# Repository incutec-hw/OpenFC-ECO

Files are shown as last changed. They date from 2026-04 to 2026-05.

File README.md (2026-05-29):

# OpenFC-Lite-Mini

Open-source Betaflight flight controller — **20×20 mm**, 6-layer, 3S–6S, built around the RP2354B microcontroller. Compact and low-cost: external RX over UART, microSD blackbox, analog OSD.

<p>
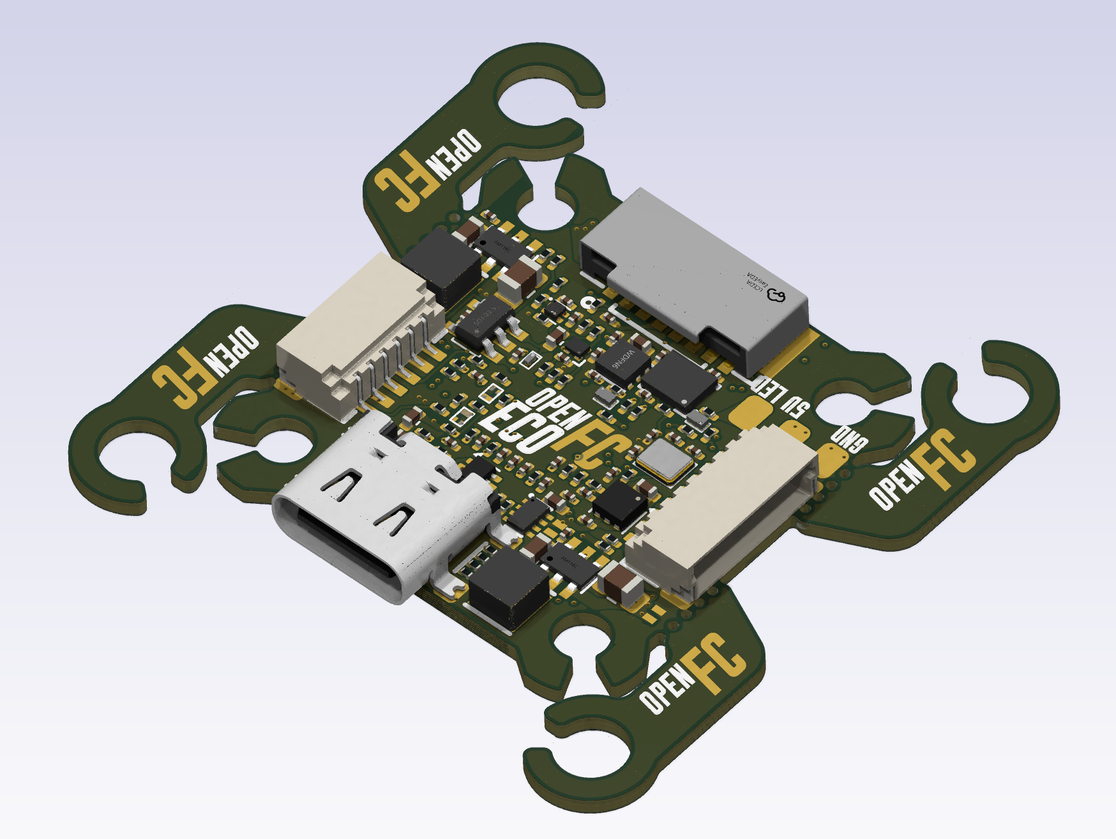
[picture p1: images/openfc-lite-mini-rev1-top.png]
OpenFC-Lite-Mini Rev 1 Top

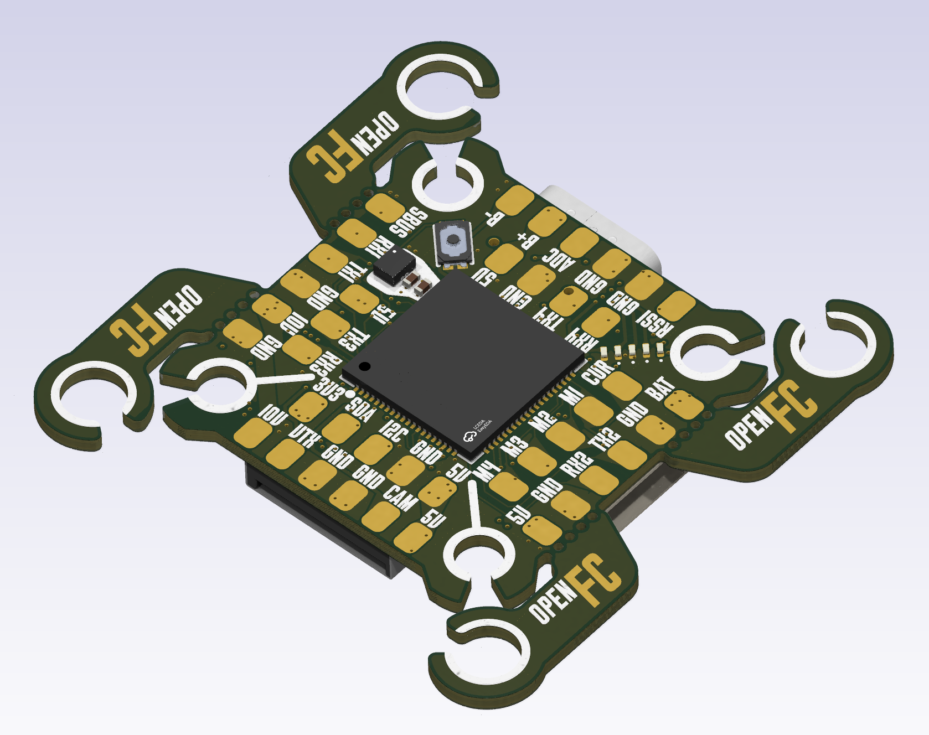
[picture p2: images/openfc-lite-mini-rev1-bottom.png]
OpenFC-Lite-Mini Rev 1 Bottom

</p>

> This repository is the **Mini** (20×20). A larger **OpenFC-Lite** (30.5×30.5 mm, bigger pads, more I/O, full-size SD) will be derived from this design once the Mini is finalized.

## At a glance

| | |
|---|---|
| MCU | RP2354B — dual Cortex-M33 @ 150 MHz, 2 MB flash, QFN-80 |
| IMU | 6-axis, SPI0 (LGA-14 footprint — part TBD, see [IMU](#imu)) |
| Blackbox | microSD card slot (TF-021B-H265) on SPI1 |
| OSD | analog, PIO-driven (sync separator + op-amp + SPDT switch) |
| Power | 3S–6S; switchable 10V (VTX/cam) + always-on 5V |
| Size | 20×20 mm, 6-layer |
| RX | external, over UART |
| USB | USB-C, USB-CDC for configuration |

Intentionally omitted to keep it small and cheap: barometer, integrated ELRS receiver, onboard WS2812B LEDs (LED-strip pad only), onboard SPI blackbox flash (microSD instead).

## Status

Rev 1 boards have been received and brought up. The custom Betaflight target builds and flashes; USB enumeration, IMU, SD card blackbox, and the switchable 10V VTX rail are confirmed working on bench. Bring-up of motors, external RX, and the analog OSD chain is in progress. See the [Rev 2 Change List](#rev-2-change-list) for hardware fixes scheduled for the next revision.

## Specifications

### Core
- **MCU:** RP2354B — dual-core ARM Cortex-M33 @ 150 MHz, 2 MB integrated stacked flash, QFN-80
- **IMU:** 6-axis MEMS on SPI0, dedicated 1.8V analog LDO (see [IMU](#imu))
- **Blackbox:** TF-021B-H265 microSD card slot on SPI1
- **USB:** USB-C, USB-CDC for configuration

### Power tree
| Rail | Source | Regulator | Notes |
|---|---|---|---|
| +10V (switchable) | +BATT | LMR51430YFDDCR (U3, 3A) | EN gated by GPIO11 (PINIO1). VTX/cam rail. 4.7µH / 22µF 16V / FB 100k:6.49k → 9.85V. |
| +5V (always-on) | +BATT | LMR51430YFDDCR (U4, 3A) | 4.7µH inductor. |
| +5V (USB/BATT mux) | +5V_BUCK + +5V_USB | TPS2116DRLR (U5) | Auto-selects active source. |
| +3.3V | +5V | LP5912-3.3DRVR (U7) | 500 mA LDO. |
| +1.8V (gyro analog) | +5V | NCV8187AMT180TAG (U6) | Isolated supply for IMU noise rejection. |
| +1.1V (MCU core) | +3.3V | RP2354B internal VREG | — |

### Motor outputs
- 4× PIO-driven DShot outputs (DShot600, bidirectional telemetry supported)
- M1=GPIO31, M2=GPIO30, M3=GPIO29, M4=GPIO28

### Connectors
- **USB-C** — configuration and firmware flashing
- **U8** — 6-pin SMD JST SH digital VTX connector (matches Betaflight standard: +10V/GND/TX/RX/GND/SBUS)
- **P1** — 8-pin TH JST SH ESC harness *(reversed pinout on Rev 1 — must mirror + add telem in Rev 2)*
- **J7/J8** — I2C0 expansion pads (SDA/SCL, with pull-ups to 3.3V)

### Serial / I/O
- **UART0** (GPIO0/1) — digital VTX / MSP DisplayPort
- **UART1** (GPIO22/21) — external serial RX (CRSF/SBUS/etc.)
- **PIO UART0** (GPIO2/3) — software UART, default GPS
- **PIO UART1** (GPIO26/27) — software UART, spare
- **I2C0** (GPIO16/17) — external expansion
- **SPI0** (GPIO18/19/20, CS=GPIO14, INT=GPIO13) — IMU
- **SPI1** (GPIO42/43/44, CS=GPIO46) — microSD blackbox

### Analog inputs
- VBAT sense (GPIO41) — 100k/10k divider, 11:1 ratio, 1k+100nF RC filter
- Current sense (GPIO40) — onboard sense circuit, 1k+100nF RC filter
- RSSI (GPIO45) — 1k+100nF RC filter
- External ADC (GPIO47) — 1k+100nF RC filter

### Additional
- Addressable LED strip output (GPIO23, PIO2)
- Status LED (GPIO12)
- Beeper output (GPIO6)
- 10V rail enable (GPIO11) — exposed as PINIO1/USER1 in firmware

### Analog OSD
- TLV3201AIDBVR (U20) — fast comparator, sync separator on incoming composite video
- TLV9061IDPWR (U19) — op-amp output buffer to the camera signal
- SN74LVC1G3157DTBR (U18) — SPDT analog switch: camera passthrough, black-pixel inject, white-pixel inject
- Driven by RP2354B PIO2 — pixel-level timing for character overlay on PAL/NTSC composite

## IMU

The IMU footprint is LGA-14 (2.5×3 mm), routed with pins 2/3 → GND and pins 10/11 → NC, so it accepts **both TDK (ICM-426xx/456xx) and ST (LSM6D*) families**. Choosing the IMU is a part-population decision, not a layout change.

- **Rev 1** populates **LSM6DSV16XTR** for development only.
- **The Rev 2 IMU is not yet decided** — to be selected after more bench and flight testing.
- Note: TDK parts use a CLKIN line to eliminate sample-timing jitter; ST parts have no CLKIN/SYNC. This couples to the SPI-bus cleanup in the change list below.

## Firmware

A custom Betaflight target (`OPENFC_LITE_MINI_RP2350B`, `MANUFACTURER_ID = OPFC`, `FC_TARGET_MCU = RP2350B`) defines:

- Motor map matching the Rev 1 silkscreen (M1..M4 = GPIO31..GPIO28)
- `USE_SDCARD_SPI` on SPI1 for blackbox
- `USE_PINIO` on GPIO11 for the switchable 10V VTX rail
- FB_OSD framework wired but disabled by default (enable once the analog OSD chain is verified on hardware — note the RP2350B FB_OSD driver is still an open upstream PR stack)

Build (requires a Betaflight checkout with `pico-sdk` and the BF-pinned ARM toolchain):

```sh
make picotool_install
make arm_sdk_install
make CONFIG=OPENFC_LITE_MINI_RP2350B
```

Output is a `.uf2` in `obj/`. Hold BOOTSEL, plug in USB, and drag the UF2 onto the `RP2350` mass-storage drive that mounts.

## PIO Allocation

The RP2350B has 3 PIO blocks × 4 state machines (12 total):

| Block | Function |
|---|---|
| PIO0 | DShot motor output (4 SMs, one per motor) |
| PIO1 | Software UART (PIO UART0 + PIO UART1 — TX and RX programs) |
| PIO2 | LED strip + analog OSD pixel timing |

## Revision History

| Rev | Status | Notes |
|---|---|---|
| **Rev 1** | current | Received and in bench bring-up |
| **Rev 2** | in design | See [Rev 2 Change List](#rev-2-change-list) |

## Rev 2 Change List

Schematic changes for the next revision. **Schematic and board edits are done manually** — this list is the spec to run down.

Legend: 🔧 field swap (value/part only) · 🔌 wiring / topology change · 🔍 decision / investigation · ✅ resolved / done on Rev 2 schematic

### Power
- ✅ **HW-5 — U3/U4 bucks**: LMR51420 (2A) → **LMR51430YFDDCR** (3A, C5219261) — fitted, same SOT-23-6. *Clean the `TI ` prefix out of the MPN field so LCSC/MPN exact-match works for BOM/assembly.*
- ✅ **HW-2 — R30** (10V FB, R29=100k top): 6.8k → **6.49k** (E96, what was in stock). Vout = 0.6·(1 + 100/6.49) = **9.85V** (~1.5% low — fine).
- ✅ **HW-1 — C28** (10V buck output cap): **kept 22µF 16V X5R 0603** (decided against 25V). Voltage margin OK (10V on 16V); DC-bias derates effective C to ~7–11µF, which with the 4.7µH inductor raises 10V ripple but is acceptable for a **digital** VTX rail.
- ✅ **HW-3 — L2/L3 inductors**: **both rails = 4.7µH (XRTC303020D4R7MBCA)** (decided against 10µH on L2). 10V ripple ≈1.17A p-p at 6S; peak well under the 3A part. *Verify the inductor Isat ≥ ~4A.*
- ✅ **HW-8 — U6 gyro LDO**: **kept NCV8187AMT180TAG** (300 mA) for its PSRR — electrically ample (gyro analog is single-digit mA). ⚠️ BF §3.1.2 lists ≥500 mA; confirm whether that's hard-gated at submission. Low stock → consign if needed.

### MCU / USB (per Raspberry Pi RP2350 datasheet)
- ✅ **R12/R13/R14**: **no change** — keep all at 30Ω. USB FS is impedance-tolerant (30 vs 27Ω inaudible to enumeration); R14 (VREG_AVDD RC filter) 30 vs 33Ω is negligible. Single resistor value = better DFM.
- 🔍 **D1 — USB ESD (USBLC6-2P6)**: removed on current schematic. ⚠️ **Recommend restoring.** USB is the most-handled / most-exposed interface; the RP2354B PHY isn't rated for system-level (IEC 61000-4-2 8kV) ESD, and the part is tiny/cheap/low-C. The "inconsistency" argument favors adding TVS to the *other* exposed I/O, not stripping USB. **Pending final call.**

### LEDs
- ✅ All indicator LEDs **0201 → 0402** (0201 too fragile — broke during nut install).
- ✅ **HW-4 — D2** (LED0 status, GPIO12): green → **blue** (XL-1005UBC, C22355736). BF §3.1.4.6.
- ✅ **LED series resistors recalculated for ~1mA** (greens = XL-1005UGC, C965793). Vf@1mA estimated: blue ≈2.75V, green ≈2.6V.

  | LED | Color | Source | Old R | **New R (E24)** | I |
  |---|---|---|---|---|---|
  | D2 (LED0) | Blue | GPIO12 (~3.3V) | 30R | **510Ω** | ~1.0mA |
  | D7 | Green | +3.3V | 30R | **680Ω** | ~1.0mA |
  | D5 | Green | +5V (5V_BUCK) | 200R | **2.4kΩ** | ~1.0mA |
  | D4 | Green | +10V | 470R | **7.5kΩ** | ~1.0mA |

  D2/D7 sit on 3.3V with low headroom → current is Vf-sensitive; if dim, D2→430Ω, D7→560Ω. Optional: D2→330Ω (~2mA) for daylight pre-arm visibility.

### Signals / connectivity (wiring — manual)
- 🔌 **SPI0 cleanup**: group **GYRO_CS** into the SPI bus (with SCK/MOSI/MISO); drop the IMU **CLKIN/SYNC** net (GPIO15) — ST gyros have no SYNC. Same regroup for **FLASH_CS** (SD). ⚠️ If a TDK IMU is chosen, CLKIN is useful — couple to the IMU decision.
- ✅ **SBUS inverter removed** (GPIO9). Confirmed safe: BF PICO inverts at the RP2350 pad IO-mux (`gpio_set_inover/outover(GPIO_OVERRIDE_INVERT)`), auto-set for SBUS, works on native + PIO UARTs. The SBUS line wires straight to a UART/PIO-UART **RX** GPIO; firmware inverts.
- 🔌 **HW-6 — ESC connector P1**: mirror reversed pinout **+ add telemetry pin** (BF 8-pin: Current = pin 3, Telem = pin 4). **Safety-critical** — current pinout shorts VBAT to a GPIO on a standard BF harness.
- 🔌 **HW-7** — Add **battery reverse-polarity protection** (PMOS RPP).
- ✅ **HW-11 — Beeper**: done — **N-MOS low-side switch** (Q2 DMN1150UFB-7B, R20 1k gate, R23 100k pulldown, BEEPER = GPIO6). Better than the NPN spec. *Verify: (1) flyback diode is across the buzzer (cathode → +supply, anode → drain), not just the FET body diode; (2) DMN1150UFB-7B is logic-level (turns on hard at 3.3V).*
- 🔌 **SD card**: wire compatible with both SPI and SDIO; use SPI for now (see SDIO decision below).

### Decisions / investigations
- 🔍 **IMU** — undecided for Rev 2; see [IMU](#imu).
- ✅ **U5 power MUX** — **TPS2116DRLR** confirmed (auto-select USB/BATT).
- ✅ **SDIO on Pico** — **stay on SPI.** Betaflight PICO supports SD blackbox over **SPI only** (PR #14567); no SDIO under `src/platform/PICO/`, no open PR. SDIO would give ~10× throughput (~25 MB/s vs ~2 MB/s — needed for 4kHz+ full-field logging) but requires a 4-bit HW bus *and* firmware that doesn't exist. SPI1 microSD is correct.
- ✅ **CRIT-2 — motor order**: keep reversed silk (eases routing); **resolve in the BF target's DShot motor resource order** so M1–M4 map to the pads. Documented in the target.
- 🔍 **CRIT-3 — FB_OSD upstream**: the RP2350B analog-OSD driver PR stack (#14882) is still open; no flyable upstream binary yet. Track before tape-out.
- ✅ **SWD connector** — **not adding.** RP2354B flashes over USB (UF2/BOOTSEL); SWD is only for live debug. Optional test pads cost nothing but no connector needed.

## Repository Structure

```
OpenFC-Lite-Mini/
├── README.md
├── LICENSE
├── hardware/                ← KiCad 9 project, libraries, and production files
│   ├── OpenFC.kicad_pro     ← Project file
│   ├── OpenFC.kicad_pcb     ← PCB layout
│   ├── OpenFC.kicad_sch     ← Top-level schematic (hierarchical)
│   ├── *.kicad_sch          ← Sub-sheets
│   ├── lib.kicad_sym        ← Project-local symbol library
│   ├── lib.pretty/          ← Project-local footprint library
│   ├── lib.3dshapes/        ← Project-local 3D models
│   ├── production/          ← JLCPCB production exports, per revision
│   └── tools/               ← Analysis scripts (Python, kicad-skip / pcbnew API)
└── images/                  ← Board renders
```

All symbol, footprint, and 3D model libraries are project-local — no external library setup required.

## Schematic Hierarchy

- `OpenFC.kicad_sch` — top-level
- `rp2350a.kicad_sch` — RP2354B microcontroller and supporting circuitry
- `power.kicad_sch` — power supply and regulation (10V buck, 5V buck, 3.3V/1.8V LDOs, 5V mux)
- `imu.kicad_sch` — 6-axis IMU on SPI0 (LGA-14 2.5×3 footprint; Rev 1 populates LSM6DSV16XTR for dev — see [IMU](#imu))
- `osd.kicad_sch` — analog OSD chain (TLV3201 sync sep + TLV9061 buffer + SN74LVC1G3157 switch)
- `blackbox.kicad_sch` — TF-021B-H265 microSD card slot
- `pads.kicad_sch` — solder pads and connectors

## License

Hardware licensed under [CERN-OHL-S-2.0](https://ohwr.org/cern_ohl_s_v2.txt). See [LICENSE](LICENSE) for details.

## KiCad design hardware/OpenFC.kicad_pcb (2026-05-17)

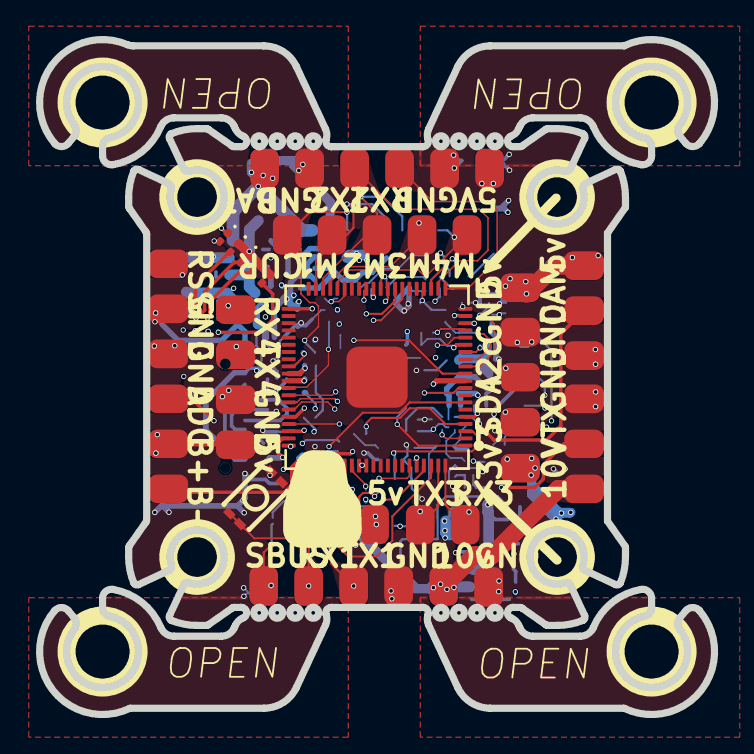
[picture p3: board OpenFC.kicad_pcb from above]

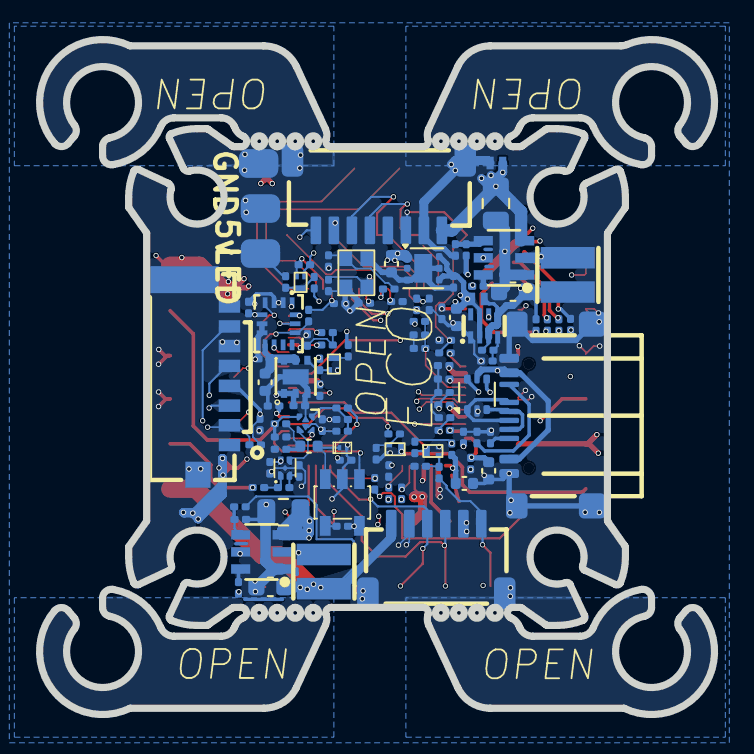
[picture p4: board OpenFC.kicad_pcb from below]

Board: 6 copper layers, 37.5 x 37.5 mm, 164 parts (113 on the bottom side), 93 nets.

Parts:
C1, C2, C3, C4, C5, C7, C8, C9, C11, C12, C13, C14, C15, C16, C17, C19, C22, C26, C27, C31, C32, C35, C36, C39, C41, C42, C43: 100n; C_0201_0603Metric
C6, C10: 20p; C_0201_0603Metric
C18, C20, C21, C23, C30: 4.7uF; C_0402_1005Metric
C24, C25: 4.7uF 50v; C_0805_2012Metric
C28, C29: 22uF; C_0603_1608Metric
C33, C34: 22uF; C_0402_1005Metric
C38: 470p; C_0201_0603Metric
C40: 1uF; C_0402_1005Metric
Card1: TF-021B-H265; TF-SMD_TF-021B-H265
D1: USBLC6-2P6; SOT-666
D2, D4, D5, D7, D10: LED_1_Green; LED_0201_0603Metric
D3, D6: RB161QS-40_C28646385; SOD-882_L1.0-W0.6-RD
D9: SDM02U30LP3-7B; X3-DFN0603-2_L0.6-W0.3-RD
J1, J2, J4, J5, J7, J8, J10, J11, J12, J13, J14, J15, J18, J21, J22, J25, J26, J27, J28, J29, J30, J31, J32, J33, J34, J35, J36, J37, J38, J39, J40, J41, J42, J43, J44, J45, J46, J47, J48, J49, J50, J52, J53, J54: 5V; small_pad
L1: AOTA-B201610S3R3-101-T; IND-SMD_L2.0-W1.6_AOTA-B201610S3R3-101-T
L2, L3: XRTC303020D4R7MBCA; IND-SMD_L3.0-W3.0_AFE303020S
P1: SM08B-SRSS-TB(LF)(SN); CONN-TH_SM08B-SRSS-TB-LF-SN
Q1, Q2, Q3, Q4: DMN1150UFB-7B; DFN-3L_L1.0-W0.6-P0.65-BR
R1, R21, R23, R27, R29, R31: 100k; R_0201_0603Metric
R2, R10, R11, R15, R24, R35, R39: 10k; R_0201_0603Metric
R3, R4: 5.1k; R_0201_0603Metric
R5, R6, R7, R8, R19, R20: 1k; R_0201_0603Metric
R9, R26, R34, R40: 200R; R_0201_0603Metric
R12, R13, R14, R16, R36: 30R; R_0201_0603Metric
R17, R18, R22, R25: 2.2k; R_0201_0603Metric
R28: 39k; R_0201_0603Metric
R30: 6.8k; R_0201_0603Metric
R32: 13.7k; R_0201_0603Metric
R33, R46, R47: 470R; R_0201_0603Metric
R41, R48: 75R; R_0201_0603Metric
R42: 3.9k; R_0201_0603Metric
R43: 12k; R_0201_0603Metric
R44: 1.4k; R_0201_0603Metric
R45: 680R; R_0201_0603Metric
U1: TS2306A 240GF MSM 9_C2976675; SW-SMD_4P-L3.0-W2.0-P0.85-LS3.5
U2: RP2354B_C39843328; QFN-80_L10.0-W10.0-P0.40-TL-EP3.4
U3, U4: LMR51420YFDDCR; SOT-23-6_L2.9-W1.6-P0.95-LS2.9-BL
U5: TPS2116DRLR; SOT-583-8_L2.1-W1.6-P0.50-LS1.6-BL
U6: NCV8187AMT180TAG; WDFN-6_L2.0-W2.0-P0.65-BL-EP
U7: LP5912-3.3DRVR; WSON-6-1EP_2x2mm_P0.65mm_EP1x1.6mm
U8: SM06B-SRSS-TB(LF)(SN); CONN-SMD_SM06B-SRSS-TB-LF-SN
U9: LSM6DSV16XTR; LGA-14_L3.0-W2.5-P0.50-BR
U18: SN74LVC1G3157DTBR; X2SON-6_L1.0-W0.8-BL
U19: TLV9061IDPWR; X2SON-4_L0.8-W0.8-P0.48-TL-DPW
U20: TLV3201AIDBVR; SOT-23-5_L3.0-W1.7-P0.95-LS2.8-BR
USB1: TYPE-C 16P QTWT; USB-TYPE-C-SMD_TYPE-C-16P-QTWT
X1: XTM25012000JT00351001; CRYSTAL-SMD_4P-L2.5-W2.0-BL-A

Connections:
+1.1V: C1.1, C2.1, C3.1, C20.1, L1.1, U2.10 (DVDD), U2.32 (DVDD), U2.51 (DVDD), U2.65 (VREG_FB)
+1.8V_GYRO: C33.1, C35.1, U6.5 (SNS), U6.6 (OUT), U9.8 (Vdd)
+3.3V: C5.1, C7.1, C8.1, C9.1, C11.1, C12.1, C13.1, C17.1, C18.1, C19.1, C34.1, C36.1, C39.1, C41.1, C42.1, C43.1, Card1.4 (VDD), J28.1 (Pin_1_1), Q3.1 (G), R9.1, R10.1, R14.1, R15.2, R17.1, R18.2, R22.1, R24.2, R36.1, R39.1, R43.2, U2.5 (IOVDD), U2.15 (IOVDD), U2.24 (IOVDD), U2.29 (IOVDD), U2.41 (IOVDD), U2.50 (IOVDD), U2.60 (IOVDD), U2.64 (VREG_VIN), U2.68 (USB_OTP_VDD), U2.69 (QSPI_IOVDD), U2.76 (IOVDD), U7.1 (OUT), U9.5 (Vdd_IO), U18.5 (VCC), U19.5 (V+), U20.5 (VCC)
+5V: C30.1, C31.1, C32.1, D3.1 (C), D10.2 (A), J4.1 (Pin_1_1), J5.1 (Pin_1_1), J22.1 (Pin_1_1), J25.1 (Pin_1_1), J30.1 (Pin_1_1), J40.1 (Pin_1_1), J47.1 (Pin_1_1), R25.1, R35.2, U5.2 (VOUT), U5.7 (VOUT), U6.1 (IN), U6.2 (EN), U7.4 (EN), U7.6 (IN)
+5V_BUCK: C29.1, D3.2 (A), L3.2, R27.2, R31.2, R34.1, U5.3 (VIN1), U5.5 (MODE)
+5V_USB: D1.5, U5.6 (VIN2), USB1.A4 (VBUS), USB1.A9 (VBUS)
+10V: C28.1, J38.1 (Pin_1_1), J45.1 (Pin_1_1), L2.2, R29.2, R33.1, U8.1
+BATT: C24.1, C25.1, D6.1 (C), J29.1 (Pin_1_1), P1.1, R1.1, U3.3 (VIN), U4.3 (VIN), U4.5 (EN)
/BLACKBOX/FLASH_CS: Card1.2 (CD/DAT3), R39.2, U2.57 (GPIO46_ADC6)
/BLACKBOX/SPI1.MISO: Card1.7 (DAT0), U2.55 (GPIO44_ADC4)
/BLACKBOX/SPI1.MOSI: Card1.3 (CMD), U2.54 (GPIO43_ADC3)
/BLACKBOX/SPI1.SCK: Card1.5 (CLX), U2.53 (GPIO42_ADC2)
/I2C_SCL: J15.1 (Pin_1_1), R17.2, U2.17 (GPIO17)
/I2C_SDA: J18.1 (Pin_1_1), R18.1, U2.16 (GPIO16)
/IMU/GYRO_CS: R15.1, U2.13 (GPIO14), U9.12 (CS)
/IMU/GYRO_INT: U2.12 (GPIO13), U9.4 (INT1)
/IMU/SPI0.CLKIN: U2.14 (GPIO15), U9.9 (INT2)
/IMU/SPI0.MISO: U2.20 (GPIO20), U9.1 (SDO/SA0)
/IMU/SPI0.MOSI: U2.19 (GPIO19), U9.14 (SDA)
/IMU/SPI0.SCK: U2.18 (GPIO18), U9.13 (SCL)
/LED: J10.1 (Pin_1_1), R26.2
/OSD/OSD_EN: U2.2 (GPIO5), U18.6 (S)
/OSD/OSD_LVL: R42.2, R43.1, R44.2, U18.1 (B2)
/OSD/OSD_SYNC: U2.3 (GPIO6), U20.1 (OUT)
/OSD/OSD_W: R42.1, U2.1 (GPIO4)
/OSD/VIDEO_IN: J32.1 (Pin_1_1), R41.1, R45.2, U18.3 (B1)
/OSD/VIDEO_OUT: J34.1 (Pin_1_1), R48.2
/OSD/VID_DC: C40.2, D9.1 (C), U20.3 (IN+)
/OSD/VID_FILT: C38.1, C40.1, R45.1
/PADS/ADC2: C16.2, J11.1 (Pin_1_1), R8.2
/PADS/BUZZER-: J21.1 (Pin_1_1), Q2.3 (D)
/PADS/CURRENT: C14.2, J33.1 (Pin_1_1), P1.3, R6.2
/PADS/DIGITAL_RX: J49.1 (Pin_1_1), U2.78 (GPIO1), U8.4
/PADS/DIGITAL_TX: J48.1 (Pin_1_1), U2.77 (GPIO0), U8.3
/PADS/M1: J35.1 (Pin_1_1), P1.5, U2.39 (GPIO31)
/PADS/M2: J37.1 (Pin_1_1), P1.6, U2.38 (GPIO30)
/PADS/M3: J39.1 (Pin_1_1), P1.7, U2.37 (GPIO29)
/PADS/M4: J41.1 (Pin_1_1), P1.8, U2.36 (GPIO28)
/PADS/PIOUART0_RX: J44.1 (Pin_1_1), U2.80 (GPIO3)
/PADS/PIOUART0_TX: J43.1 (Pin_1_1), U2.79 (GPIO2)
/PADS/PIOUART1_RX: J54.1 (Pin_1_1), U2.28 (GPIO27)
/PADS/PIOUART1_TX: J52.1 (Pin_1_1), U2.27 (GPIO26)
/PADS/RSSI: C15.2, J2.1 (Pin_1_1), R7.2
/PADS/SBUS: J53.1 (Pin_1_1), R19.2, U8.6
/POWER/1.8V_PG: Q4.1 (G), R35.1, U6.4 (PG)
/POWER/10V_ENABLE: U2.9 (GPIO11), U3.5 (EN)
/RP2350A/ADC_VBAT: C4.2, R1.2, R2.2, U2.52 (GPIO41_ADC1)
/RP2350A/BEEPER: R20.2, U2.4 (GPIO7)
/RP2350A/D+: D1.6, R13.2
/RP2350A/D+_C: D1.1, USB1.A6 (DP1), USB1.B6 (DP2)
/RP2350A/D-: D1.4, R12.1
/RP2350A/D-_C: D1.3, USB1.A7 (DN1), USB1.B7 (DN2)
/RP2350A/LED0: R16.1, U2.11 (GPIO12)
/RP2350A/LED_STRIP_L: Q3.2 (S), R22.2, U2.23 (GPIO23)
/RP2350A/SBUS_INVERT: Q1.3 (D), R24.1, U2.7 (GPIO9)
/RP2350A/XIN: C6.2, U2.30 (XIN), X1.1
/RP2350A/XOUT: R5.1, U2.31 (XOUT)
/UART1_RX: J8.1 (Pin_1_1), U2.21 (GPIO21)
/UART1_TX: J12.1 (Pin_1_1), U2.22 (GPIO22)
GND: C1.2, C2.2, C3.2, C4.1, C5.2, C6.1, C7.2, C8.2, C9.2, C10.1, C11.2, C12.2, C13.2, C14.1, C15.1, C16.1, C17.2, C18.2, C19.2, C20.2, C21.2, C22.1, C23.2, C24.2, C25.2, C28.2, C29.2, C30.2, C31.2, C32.2, C33.2, C34.2, C35.2, C36.2, C38.2, C39.2, C41.2, C42.2, C43.2, Card1.6 (VSS), Card1.9, Card1.10, D1.2, D2.1 (K), D4.1 (K), D5.1 (K), D6.2 (A), D7.1 (K), D9.2 (A), J1.1 (Pin_1_1), J7.1 (Pin_1_1), J13.1 (Pin_1_1), J14.1 (Pin_1_1), J26.1 (Pin_1_1), J27.1 (Pin_1_1), J31.1 (Pin_1_1), J36.1 (Pin_1_1), J42.1 (Pin_1_1), J46.1 (Pin_1_1), J50.1 (Pin_1_1), P1.2, P1.9, P1.10, Q1.2 (S), Q2.2 (S), Q4.2 (S), R2.1, R3.1, R4.1, R21.1, R23.1, R28.2, R30.2, R32.2, R41.2, R44.1, R46.1, U1.1, U2.62 (VREG_PGND), U2.81 (GND), U3.1 (GND), U4.1 (GND), U5.1 (GND), U6.3 (GND), U6.7 (EP), U7.3 (GND), U7.5 (PG), U7.7 (EP), U8.2, U8.5, U8.7, U8.8, U9.2 (SDx/AH1/Qvar1), U9.3 (SCx/AH2/Qvar2), U9.6 (GND), U9.7 (GND), U18.2 (GND), U19.3 (V-), U20.2 (GND), U20.4 (IN-), USB1.0 (EH), USB1.A1 (GND), USB1.A12 (GND), X1.2 (GND), X1.4 (GND)
unnamed: C10.2, R5.2, X1.3
unnamed: D2.2 (A), R16.2
unnamed: D4.2 (A), R33.2
unnamed: D5.2 (A), R34.2
unnamed: D7.2 (A), R36.2
unnamed: D10.1 (K), R40.1
unnamed: Q1.1 (G), R19.1, R21.2
unnamed: Q2.1 (G), R20.1, R23.2
unnamed: Q3.3 (D), R25.2, R26.1
unnamed: Q4.3 (D), R40.2
unnamed: R11.1, U1.2
unnamed: C21.1, R9.2, U2.59 (ADC_AVDD)
unnamed: R6.1, U2.49 (GPIO40_ADC0)
unnamed: R7.1, U2.56 (GPIO45_ADC5)
unnamed: R8.1, U2.58 (GPIO47_ADC7)
unnamed: R11.2, U2.75 (QSPI_SS)
unnamed: C22.2, R10.2, U2.35 (RUN)
unnamed: R12.2, U2.66 (USB_DM)
unnamed: R13.1, U2.67 (USB_DP)
unnamed: C23.1, R14.2, U2.61 (VREG_AVDD)
unnamed: L1.2, U2.63 (VREG_LX)
unnamed: C26.2, U3.6 (CB)
unnamed: R29.1, R30.1, U3.4 (FB)
unnamed: C26.1, L2.1, U3.2 (SW)
unnamed: C27.2, U4.6 (CB)
unnamed: R31.1, R32.1, U4.4 (FB)
unnamed: C27.1, L3.1, U4.2 (SW)
unnamed: R27.1, R28.1, U5.4 (PR1)
unnamed: U18.4 (A), U19.4 (IN+)
unnamed: R46.2, R47.1, U19.2 (IN-)
unnamed: R47.2, R48.1, U19.1 (OUT)
unnamed: R3.2, USB1.A5 (CC1)
unnamed: R4.2, USB1.B5 (CC2)

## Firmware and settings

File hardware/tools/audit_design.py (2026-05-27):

#!/usr/bin/env python3
"""
OpenFC-Lite Design Audit.

Parses the KiCad 9 design using kicad-skip (schematics) and pcbnew (PCB netlist)
and produces a comprehensive hardware inventory + Betaflight MFG validation report.

Run with KiCad's bundled Python so pcbnew is available:
  /Applications/KiCad/KiCad.app/Contents/Frameworks/Python.framework/Versions/Current/bin/python3 \
    hardware/tools/audit_design.py
"""

from __future__ import annotations

import collections
import os
import re
import sys
from pathlib import Path

HW = Path(__file__).resolve().parents[1]
ROOT_SCH = HW / "OpenFC.kicad_sch"
PCB = HW / "OpenFC.kicad_pcb"
OUT = HW / "tools" / "design_audit.md"

# ---------- Parsers ----------

# kicad-skip: path setup for user-level install
sys.path.insert(0, "/Users/stan/Library/Python/3.13/lib/python/site-packages")
try:
    from skip import Schematic
except ImportError:
    print("ERROR: kicad-skip not available. pip install kicad-skip", file=sys.stderr)
    sys.exit(1)

try:
    import pcbnew  # type: ignore
except ImportError:
    print("ERROR: pcbnew not on path. Run with KiCad bundled Python.", file=sys.stderr)
    sys.exit(1)


# ---------- Schematic walk ----------

def list_sheets(root_sch: Path):
    """Return list of (sheetname, sheetfile) pairs referenced from root."""
    s = Schematic(str(root_sch))
    out = []
    for sh in s.sheet:
        props = {p.name: p.value for p in sh.property}
        out.append((props.get("Sheetname", "?"), props.get("Sheetfile", "?")))
    return out


def collect_symbols(sch_path: Path):
    """Parse a schematic; return list of dicts per placed symbol."""
    try:
        s = Schematic(str(sch_path))
    except Exception as e:
        print(f"  WARN: cannot parse {sch_path.name}: {e}", file=sys.stderr)
        return []
    out = []
    for sym in s.symbol:
        try:
            lib_id = sym.lib_id.value
        except Exception:
            continue
        props = {p.name: p.value for p in sym.property}
        ref = props.get("Reference", "?")
        if ref.startswith("#"):
            continue  # power flag / gnd
        # Filter out stray power-flag symbols mis-refed in sub-sheets (e.g. blackbox
        # sub-sheet has U1..U9 that are actually +3.3V / GND power symbols).
        lib_id_lower = lib_id.lower()
        if lib_id_lower.startswith("power:") or lib_id_lower == "power":
            continue
        out.append({
            "sheet": sch_path.stem,
            "ref": ref,
            "value": props.get("Value", ""),
            "footprint": props.get("Footprint", ""),
            "mpn": props.get("MPN", ""),
            "lcsc": props.get("LCSC_Part", "") or props.get("LCSC", ""),
            "mfr": props.get("Manufacturer", ""),
            "description": props.get("Description", ""),
            "lib_id": lib_id,
            "dnp": bool(getattr(sym, "dnp", None) and sym.dnp.value),
            "on_board": bool(getattr(sym, "on_board", None) and sym.on_board.value),
        })
    return out


# ---------- PCB walk ----------

def load_pcb(pcb_path: Path):
    return pcbnew.LoadBoard(str(pcb_path))


def footprint_index(board):
    """ref -> {pads: {pad_num: netname}, funcs: {pad_num: pinfunc}, ...}"""
    idx = {}
    for fp in board.GetFootprints():
        r = fp.GetReference()
        pads = {}
        funcs = {}
        for pad in fp.Pads():
            num = pad.GetNumber()
            pads[num] = pad.GetNetname() or ""
            try:
                funcs[num] = pad.GetPinFunction() or ""
            except Exception:
                funcs[num] = ""
        idx[r] = {
            "value": fp.GetValue(),
            "footprint": fp.GetFPID().GetLibItemName().c_str() if hasattr(fp.GetFPID(), "GetLibItemName") else "",
            "pads": pads,
            "funcs": funcs,
        }
    return idx


def net_to_refpins(board):
    """netname -> list of (ref, pad_num, pad_name/function)"""
    d = collections.defaultdict(list)
    for fp in board.GetFootprints():
        r = fp.GetReference()
        for pad in fp.Pads():
            name = pad.GetNetname() or ""
            d[name].append((r, pad.GetNumber(), pad.GetPinFunction() if hasattr(pad, "GetPinFunction") else ""))
    return d


# ---------- Classification ----------

FUNC_RULES = [
    ("MCU",       lambda s: s["ref"].startswith("U") and "RP235" in s["value"].upper()),
    ("IMU",       lambda s: "LSM6" in s["value"].upper() or "ICM-4" in s["value"].upper() or "MPU6" in s["value"].upper()),
    ("Buck",      lambda s: s["ref"].startswith("U") and "LMR5" in s["value"].upper()),
    ("LDO",       lambda s: s["ref"].startswith("U") and ("LP5912" in s["value"].upper() or "NCV8187" in s["value"].upper())),
    ("Power Mux", lambda s: "TPS2116" in s["value"].upper()),
    ("OSD",       lambda s: "TLV3201" in s["value"].upper() or "TLV9061" in s["value"].upper() or "LVC1G3157" in s["value"].upper() or "PI3A223" in s["value"].upper()),
    ("SD card",   lambda s: "TF-" in s["value"].upper() or "SD" == s["ref"][:2].upper() and "CARD" in s["description"].upper()),
    ("USB",       lambda s: s["ref"].startswith("USB") or "USB" in s["value"].upper() and s["ref"].startswith("J") or s["ref"] == "USB1"),
    ("Switch",    lambda s: s["ref"].startswith("SW") or "TS2306" in s["value"].upper()),
    ("Connector", lambda s: s["ref"].startswith("J") or "CONN" in s["lib_id"].upper()),
    ("Test Pad",  lambda s: s["ref"].startswith("TP")),
    ("MOSFET",    lambda s: s["ref"].startswith("Q")),
    ("Diode/LED", lambda s: s["ref"].startswith("D") and ("LED" in s["value"].upper() or "LED" in s["description"].upper())),
    ("Diode",     lambda s: s["ref"].startswith("D")),
    ("Inductor",  lambda s: s["ref"].startswith("L")),
    ("Ferrite",   lambda s: s["ref"].startswith("FB")),
    ("Resistor",  lambda s: s["ref"].startswith("R")),
    ("Capacitor", lambda s: s["ref"].startswith("C")),
    ("IC",        lambda s: s["ref"].startswith("U")),
]

def classify(sym):
    for name, fn in FUNC_RULES:
        try:
            if fn(sym):
                return name
        except Exception:
            continue
    return "Misc"


# ---------- Report builders ----------

def refs_on_net(net2rp, netname, exclude_refs=None):
    exclude_refs = set(exclude_refs or [])
    return [(r, n, f) for (r, n, f) in net2rp.get(netname, []) if r not in exclude_refs]


def find_caps_between(syms_by_ref, net2rp, netname_a, netname_b="GND"):
    """Return list of cap refs having one pad on netname_a and other on netname_b."""
    caps_on_a = {r for (r, _, _) in net2rp.get(netname_a, []) if r.startswith("C")}
    caps_on_b = {r for (r, _, _) in net2rp.get(netname_b, []) if r.startswith("C")}
    return sorted(caps_on_a & caps_on_b, key=lambda x: int(re.sub(r"\D", "", x) or 0))


def find_nets_matching(net2rp, *patterns):
    pats = [re.compile(p, re.I) for p in patterns]
    return [n for n in net2rp if any(p.search(n) for p in pats)]


def pad_net(fp_idx, ref, pad_num):
    return fp_idx.get(ref, {}).get("pads", {}).get(str(pad_num), "")


def md_table(headers, rows):
    out = ["| " + " | ".join(headers) + " |",
           "|" + "|".join(["---"] * len(headers)) + "|"]
    for row in rows:
        out.append("| " + " | ".join(str(x) for x in row) + " |")
    return "\n".join(out)


# ---------- Main audit ----------

def main():
    lines = []
    W = lines.append

    W("# OpenFC-Lite Design Audit\n")
    W(f"Generated from `{ROOT_SCH.name}` + `{PCB.name}` via kicad-skip + pcbnew.\n")

    # ---- 1. Hierarchy ----
    W("## 1. Top-level Hierarchy\n")
    sheets = list_sheets(ROOT_SCH)
    rows = []
    for name, path in sheets:
        exists = (HW / path).exists()
        rows.append([name, f"`{path}`", "yes" if exists else "**MISSING**"])
    W(md_table(["Sheetname", "File", "On disk"], rows))
    W("")
    W(f"Root schematic: `{ROOT_SCH.name}` — {len(sheets)} sub-sheet(s) referenced.\n")

    # ---- 2. Components ----
    W("## 2. Component Inventory\n")
    all_syms = []
    for name, path in sheets:
        p = HW / path
        if p.exists():
            all_syms.extend(collect_symbols(p))
    # Deduplicate by ref (symbols may appear in multiple places due to power/gnd)
    seen = {}
    for s in all_syms:
        seen.setdefault(s["ref"], s)
    syms = list(seen.values())

    W(f"Total placed refs: **{len(syms)}** (DNP excluded: "
      f"{len([s for s in syms if s['dnp']])}).\n")

    by_func = collections.defaultdict(list)
    for s in syms:
        by_func[classify(s)].append(s)

    # Print ICs, regulators, connectors etc fully; print caps/resistors summarized
    DETAIL_FUNCS = ["MCU", "IMU", "Buck", "LDO", "Power Mux", "OSD",
                    "SD card", "USB", "Switch", "MOSFET",
                    "Diode/LED", "Diode", "IC", "Inductor", "Ferrite"]
    def ref_sort_key(ref):
        m = re.match(r"([A-Za-z]+)(\d+)", ref)
        if m:
            return (m.group(1), int(m.group(2)))
        return (ref, 0)

    for fn in DETAIL_FUNCS:
        items = sorted(by_func.get(fn, []), key=lambda x: ref_sort_key(x["ref"]))
        if not items:
            continue
        W(f"### {fn} ({len(items)})\n")
        rows = []
        for s in items:
            mpn = s["mpn"] or s["value"]
            dnp = " DNP" if s["dnp"] else ""
            rows.append([s["ref"] + dnp, s["value"], mpn, s["lcsc"] or "-",
                         s["mfr"] or "-", s["footprint"].split(":")[-1] if s["footprint"] else "-",
                         s["sheet"]])
        W(md_table(["Ref", "Value", "MPN", "LCSC", "Mfr", "Footprint", "Sheet"], rows))
        W("")
    # Connector summary only (detail in section 14)
    conns = by_func.get("Connector", [])
    if conns:
        W(f"### Connector / Solder Pads ({len(conns)})\n")
        W("(full net list in section 14)\n")
        # group by footprint
        fp_count = collections.Counter((s["footprint"].split(":")[-1] or "-", s["sheet"]) for s in conns)
        rows = [[fp, sh, c] for (fp, sh), c in sorted(fp_count.items())]
        W(md_table(["Footprint", "Sheet", "Count"], rows))
        W("")

    # Passives summary
    W("### Passives summary\n")
    rows = []
    for fn in ("Resistor", "Capacitor", "Test Pad"):
        items = [s for s in by_func.get(fn, []) if not s["dnp"]]
        dnp = [s for s in by_func.get(fn, []) if s["dnp"]]
        rows.append([fn, len(items), len(dnp)])
    W(md_table(["Function", "Placed", "DNP"], rows))
    W("")

    # ---- Load PCB for net-level analysis ----
    board = load_pcb(PCB)
    fp_idx = footprint_index(board)
    net2rp = net_to_refpins(board)

    # ---- 3. Power tree ----
    W("## 3. Power Tree\n")
    W("```")
    W("+BATT -> U6 (LMR51420YFDDCR buck) -> +12V   [switchable via GPIO11 via Q?]")
    W("+BATT -> U7 (LMR51420YFDDCR buck) -> +5V_BUCK")
    W("+5V_BUCK -+")
    W("          +- U33 (TPS2116 mux) -> +5V")
    W("VBUS(USB)-+")
    W("+5V -> U13 (LP5912-3.3) -> +3.3V")
    W("+3.3V -> U36 (RP2354B VREG) -> +1.1V_CORE (DVDD)")
    W("+5V -> U21 (NCV8187 LDO) -> +1.8V_GYRO")
    W("```\n")

    regs = [
        ("U6",  "LMR51420YFDDCR", "12V buck"),
        ("U7",  "LMR51420YFDDCR", "5V buck"),
        ("U13", "LP5912-3.3DRVR", "3.3V LDO"),
        ("U21", "NCV8187AMT180TAG", "1.8V gyro LDO"),
        ("U33", "TPS2116DRLR", "5V power mux"),
    ]
    rows = []
    for ref, mpn, role in regs:
        fp = fp_idx.get(ref, {})
        pads = fp.get("pads", {})
        # summarise input / EN / output if we can infer by pin function from schematic
        # Just print key pads
        rows.append([ref, role, mpn, fp.get("footprint", "-"),
                     "; ".join(f"{k}→{v}" for k, v in sorted(pads.items(), key=lambda x: int(x[0]) if x[0].isdigit() else 99))])
    W(md_table(["Ref", "Role", "MPN", "Footprint", "Pad → Net"], rows))
    W("")

    # ---- 4. Bypass caps per rail ----
    W("## 4. Bypass caps per power rail\n")
    rails = ["+BATT", "+12V", "+5V_BUCK", "+5V", "VBUS", "+3.3V", "+1.8V_GYRO",
             "+1.1V", "+1.1V_CORE", "DVDD"]
    rows = []
    for rail in rails:
        # try exact, then with leading /
        candidates = [rail, "/" + rail, rail.lstrip("+"), "/" + rail.lstrip("+")]
        found_net = None
        for c in candidates:
            if c in net2rp:
                found_net = c
                break
        if not found_net:
            # try loose match
            loose = [n for n in net2rp if n.strip("/+").upper() == rail.strip("/+").upper()]
            if loose:
                found_net = loose[0]
        if not found_net:
            rows.append([rail, "— (net not found)", "-", "-"])
            continue
        caps = find_caps_between({}, net2rp, found_net, "GND")
        # count how many pins are on this net (fanout size)
        fanout = len(net2rp.get(found_net, []))
        rows.append([rail, found_net, len(caps), ", ".join(caps) if caps else "—"])
    W(md_table(["Rail", "Net", "# Caps to GND", "Cap refs"], rows))
    W("")
    # Also report ALL nets that look like rails
    rail_like = [n for n in net2rp if re.search(r"(^|/)(\+?\d+V|VBUS|VBAT|VDD|AVDD|DVDD|VREG)", n, re.I)]
    W("Rail-like nets present:\n")
    W(", ".join(f"`{n}`" for n in sorted(set(rail_like))))
    W("")

    # ---- 5. ADC inputs ----
    W("## 5. ADC Inputs\n")
    adc_nets = {
        "VBAT_SENSE": ["VBAT", "VBATT_SENSE", "VBAT_ADC", "BATT_ADC", "VBAT_SCALE", "BATTERY_ADC"],
        "CURR_SENSE": ["CURRENT", "I_SENSE", "CURR_ADC", "CURR_SENSE", "IMON", "CURRENT_ADC"],
        "RSSI":       ["RSSI", "RSSI_ADC"],
        "EXT":        ["EXT_ADC", "ADC_EXT", "EXT"],
    }
    # Try to find the MCU's actual ADC pins: GPIO40,41,45,47 per CLAUDE.md
    mcu_ref = "U36"
    mcu_fp = fp_idx.get(mcu_ref, {})
    # The ADC nets go to MCU pins — find them by following net back to U36
    rows = []
    for role, candidates in adc_nets.items():
        net = None
        for c in candidates:
            match = [n for n in net2rp if c.upper() in n.upper()]
            if match:
                net = sorted(match, key=len)[0]
                break
        if not net:
            rows.append([role, "— not found", "-", "-", "-"])
            continue
        # Find MCU pad carrying this net
        mcu_pad = "-"
        for p, n in mcu_fp.get("pads", {}).items():
            if n == net:
                mcu_pad = p
                break
        # Find resistors on the net
        res = [r for (r, _, _) in net2rp.get(net, []) if r.startswith("R")]
        caps = find_caps_between({}, net2rp, net, "GND")
        rows.append([role, net, mcu_pad,
                     ", ".join(sorted(set(res))) or "—",
                     ", ".join(caps) or "**NONE**"])
    W(md_table(["Role", "Net", "MCU pad", "Resistors on net", "Bypass caps to GND"], rows))
    W("")
    W("**Check**: A CURRENT-sense ADC input WITHOUT a bypass cap at the MCU pin is a "
      "Betaflight MFG-guideline violation (noise couples straight into ADC).\n")

    # ---- 6. SPI buses & CS pull-ups ----
    W("## 6. SPI Buses & CS pull-ups\n")
    spi_nets = {
        "SPI0 SCK":  [n for n in net2rp if re.search(r"SPI0?_?SCK|GYRO_?SCK|IMU_?SCK", n, re.I)],
        "SPI0 MOSI": [n for n in net2rp if re.search(r"SPI0?_?(MOSI|SDI|SDA)|GYRO_?MOSI|IMU_?MOSI", n, re.I)],
        "SPI0 MISO": [n for n in net2rp if re.search(r"SPI0?_?(MISO|SDO)|GYRO_?MISO|IMU_?MISO", n, re.I)],
        "IMU CS":    [n for n in net2rp if re.search(r"(IMU|GYRO).*CS|CS_?(IMU|GYRO)", n, re.I)],
        "SD CS":     [n for n in net2rp if re.search(r"SD.*CS|CS_?SD|BB_?CS", n, re.I)],
        "SD MOSI":   [n for n in net2rp if re.search(r"SD.*MOSI|SD.*DI|SD_?CMD", n, re.I)],
        "SD MISO":   [n for n in net2rp if re.search(r"SD.*MISO|SD.*DO|SD_?DAT0?", n, re.I)],
        "SD SCK":    [n for n in net2rp if re.search(r"SD.*SCK|SD.*CLK", n, re.I)],
    }
    rows = []
    for role, nets in spi_nets.items():
        if not nets:
            rows.append([role, "—", "-", "-"])
            continue
        net = nets[0]
        # list refs on that net
        refs = sorted(set(r for (r, _, _) in net2rp[net]))
        # resistors on net (pull-up candidates)
        rs = [r for r in refs if r.startswith("R")]
        rows.append([role, net, ", ".join(refs), ", ".join(rs) or "—"])
    W(md_table(["Signal", "Net", "Refs on net", "Resistors (pull-ups?)"], rows))
    W("")

    # Specific checks for CS pull-ups
    W("### CS pull-up check (to +3.3V)\n")
    cs_checks = []

    def find_cs_pad(ref):
        """Return (pad_num, netname) for the CS pin of a footprint, using pin function."""
        fp = fp_idx.get(ref, {})
        for p, func in fp.get("funcs", {}).items():
            if re.search(r"(^|_)CS(_|$)", func or "", re.I):
                return p, fp.get("pads", {}).get(p, "")
        return None, None

    # IMU CS -> U14 using pin function
    pad, net = find_cs_pad("U14")
    cs_checks.append((f"IMU_CS (U14 pad {pad})", net))
    # SD CS -> Card2 pad 2 (TF-021B-H265 pinout: pin2=CS/DAT3)
    for ref, fp in fp_idx.items():
        v = fp.get("value", "").upper()
        if "TF-" in v or "MICROSD" in v:
            # TF socket pad 2 = CS in SPI mode
            n = fp.get("pads", {}).get("2", "")
            cs_checks.append((f"SD_CS ({ref} pad 2)", n))
            break
    rows = []
    for role, net in cs_checks:
        if not net:
            rows.append([role, "—", "—", "—"])
            continue
        rs = [r for (r, _, _) in net2rp.get(net, []) if r.startswith("R")]
        # Does any of those R's touch +3.3V or +3V3?
        has_pullup = False
        pu_ref = "-"
        for rref in rs:
            rpads = fp_idx.get(rref, {}).get("pads", {})
            other_nets = set(rpads.values()) - {net}
            if any(re.search(r"3V3|3\.3V|VDDIO", x, re.I) for x in other_nets):
                has_pullup = True
                pu_ref = rref
                break
        rows.append([role, net, "YES" if has_pullup else "NO", pu_ref])
    W(md_table(["CS line", "Net", "Pull-up present?", "Pull-up ref"], rows))
    W("")

    # ---- 7. Status LEDs ----
    W("## 7. Status LEDs (non-WS2812)\n")
    leds = [s for s in syms if s["ref"].startswith("D") and
            ("LED" in s["value"].upper() or "LED" in (s["description"] or "").upper())]
    rows = []
    for led in sorted(leds, key=lambda x: x["ref"]):
        ref = led["ref"]
        fp = fp_idx.get(ref, {})
        pads = fp.get("pads", {})
        # LEDs usually have A/K or 1/2
        pin_nets = ", ".join(f"{k}→{v}" for k, v in pads.items())
        # Try to identify MCU pin driving it (non-rail end)
        drivers = [v for v in pads.values() if not re.search(r"\+?(\d+V|GND|VBUS|VBAT)", v, re.I)]
        rows.append([ref, led["value"], led["mpn"] or "-", pin_nets, ", ".join(drivers) or "—"])
    W(md_table(["Ref", "Value/Color", "MPN", "Pad nets", "Likely MCU-side net"], rows))
    W("")
    # Blue LED check
    blue = [l for l in leds if "BLUE" in l["value"].upper() or "BLU" in l["value"].upper()]
    W(f"Blue LED (Betaflight LED0 requirement): **{'PRESENT' if blue else 'MISSING'}** "
      f"({', '.join(l['ref'] for l in blue) or 'none'})\n")

    # ---- 8. I2C ----
    W("## 8. I2C Pull-ups\n")
    sda_net = [n for n in net2rp if re.search(r"I2C.*SDA|SDA$|/SDA", n, re.I)]
    scl_net = [n for n in net2rp if re.search(r"I2C.*SCL|SCL$|/SCL", n, re.I)]
    rows = []
    for role, nets in (("I2C_SDA", sda_net), ("I2C_SCL", scl_net)):
        if not nets:
            rows.append([role, "—", "-", "-"])
            continue
        net = nets[0]
        refs = sorted(set(r for (r, _, _) in net2rp[net]))
        rs = [r for r in refs if r.startswith("R")]
        has_pullup = False
        for rref in rs:
            rpads = fp_idx.get(rref, {}).get("pads", {})
            if any(re.search(r"3V3|3\.3V|VDDIO", x, re.I) for x in rpads.values()):
                has_pullup = True
                break
        rows.append([role, net, ", ".join(refs), "YES" if has_pullup else "**NO**"])
    W(md_table(["Signal", "Net", "Refs on net", "Pull-up to 3.3V"], rows))
    W("")

    # ---- 9. MCU pinout ----
    W("## 9. RP2354B (U36) Pinout\n")
    mcu_fp = fp_idx.get("U36", {})
    pads = mcu_fp.get("pads", {})
    rows = []
    for p in sorted(pads.keys(), key=lambda x: int(x) if x.isdigit() else 999):
        n = pads[p]
        # skip internal / power pads for clarity (keep but mark)
        rows.append([p, n])
    W(md_table(["Pad", "Net"], rows))
    W("")

    # ---- 10. OSD circuit ----
    W("## 10. OSD Circuit\n")
    osd_refs = [s["ref"] for s in syms if s["ref"] in ("U34", "U35", "U38")]
    rows = []
    for ref in osd_refs:
        fp = fp_idx.get(ref, {})
        rows.append([ref, fp.get("value"), fp.get("footprint"),
                     "; ".join(f"{k}→{v}" for k, v in fp.get("pads", {}).items())])
    W(md_table(["Ref", "Value", "Footprint", "Pad → Net"], rows))
    W("")

    # ---- 11. SD card ----
    W("## 11. SD Card (Blackbox)\n")
    sd_refs = [s for s in syms if
               "TF-" in s["value"].upper() or "MICROSD" in s["value"].upper() or
               "SD_CARD" in s["value"].upper() or "CARD" in s["description"].upper()]
    if not sd_refs:
        # look in pcb fps too
        for ref, fp in fp_idx.items():
            if "TF-" in fp.get("value", "").upper():
                sd_refs.append({"ref": ref, "value": fp["value"], "description": "", "lib_id": "",
                                "mpn": "", "lcsc": "", "footprint": fp.get("footprint", ""),
                                "mfr": "", "sheet": "", "dnp": False, "on_board": True})
    rows = []
    for s in sd_refs:
        ref = s["ref"]
        fp = fp_idx.get(ref, {})
        pads = fp.get("pads", {})
        rows.append([ref, s["value"], fp.get("footprint"),
                     "; ".join(f"{k}→{v}" for k, v in pads.items())])
    W(md_table(["Ref", "Value", "Footprint", "Pad → Net"], rows))
    W("")
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

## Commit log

2026-03-19 Initial OpenFC-ECO: stripped variant of OpenFC
    ECO variant removes baro (BMP388), blackbox flash (BY25Q128ASWIG),
    integrated ELRS receiver (ESP32-C3FH4 + SX1281), WS2812B onboard LEDs,
    and compass (LIS3MDLTR). Keeps MCU, IMU, OSD, power, and pads.
    Sub-sheets for removed peripherals still present — to be stripped
    from root schematic in KiCad. Includes eco_strip_sheets.py helper script.
    [OpenFC.kicad_pcb, OpenFC.kicad_sch, baro.kicad_sch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]
2026-03-25 Standardize repo: .gitignore, README, license, remove orphaned files
    - Standardize .gitignore to match ecosystem template
    - Fix README: correct GitHub URL, remove generic sections, remove nonexistent dirs
    - Replace LICENSE stub with full CERN-OHL-S-2.0 text
    - Remove orphaned schematics (baro, blackbox, compass, elrs, leds) — not in ECO variant
    - Delete self-referential symlink and parent OpenFC production leftovers
    - Add new footprints and 3D models (SIM, TF connectors)
    [OpenFC.kicad_pcb, OpenFC.kicad_sch, baro.kicad_sch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]
2026-04-05 WIP: add blackbox SD card sub-sheet, pre-reroute checkpoint
    - Add blackbox.kicad_sch (rebuilt via rebuild_blackbox.py with kicad-sch-api)
    for TF-021B-H265 SD card slot, replacing onboard SPI flash
    - Add hardware/tools/rebuild_blackbox.py helper
    - Update TF-SMD_TF-021B-H265 footprint
    - Save current PCB state before rerouting for DFM and IMU family compatibility
    [OpenFC.kicad_pcb, blackbox.kicad_sch]
2026-04-05 WIP: schematic updates, library modernization, audit tooling
    Schematic changes (user):
    - Add ADC bypass caps on CURRENT/RSSI/EXTERNAL (1k + 100nF RC filter)
    - Add IMU GYRO_CS 10k pull-up to +3.3V
    - Reverse P1 ESC 8-pin JST SH pinout to BF standard
    (pin1=V+, pin2=GND, pin3=Current, pin5-8=M1-M4)
    - SD card (blackbox) sub-sheet with SPI1 + FLASH_CS + decoupling
    - Other sub-sheet cleanup (rp2350a, osd, pads, power, imu)
    Footprint library:
    - Convert all 62 legacy (module ...) footprints to modern
    (footprint ...) format via pcbnew API — fixes kicad-sch-api
    "footprint not found" errors
    Tooling:
    - Add hardware/tools/audit_design.py (BF-rule design audit script)
    - Add hardware/tools/design_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
    [OpenFC.kicad_pcb, blackbox.kicad_sch, imu.kicad_sch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]
2026-04-05 Add RP2350B two-sided layout reference notes
    Research findings on what can/can't go on opposite side of PCB from
    the MCU, with direct datasheet quotes from §6.3.8.1 and RPi hardware
    design guide.
    Key constraint: C_IN, L_X (inductor), C_OUT of the core buck
    regulator MUST stay on same side as the MCU per RPi datasheet.
    Everything else (most decoupling, crystal, USB, all support chips)
    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
2026-04-06 V0.3 routed: pin remap, footprint fixes, EMC checklist, DFM prep
    Schematic (user):
    - OSD pins remapped to GPIO4-6 (OSD_W/OSD_EN/OSD_SYNC consecutive
    for FB_OSD PIO driver per BF PR#14882)
    - SBUS inverter stays on GPIO9 (valid UART1_RX)
    - Beeper moved to GPIO36
    - Various sub-sheet updates
    PCB:
    - Full board routed, bottom-side component placement
    - Resistor footprints: C_0201 -> R_0201 for correct 3D models
    - Capacitor 3D model paths fixed (were pointing to R_0201)
    - SD card footprint 3D path fixed (${KIPRJMOD}/lib.3dshapes/)
    - 2 footprint 3D paths fixed (SIM, TF-01A: /lib.3dshapes -> ${KIPRJMOD})
    Tooling & docs:
    - Add EMC checklist (hardware/tools/EMC_CHECKLIST.md)
    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
    [OpenFC.kicad_pcb, blackbox.kicad_sch, osd.kicad_sch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]
2026-04-06 Add V0.3 board renders, fix README (10V not 12V, add SD card)
    - Add 3D render screenshots (top + bottom) to images/
    - Fix voltage references: 12V -> 10V throughout README
    - Update blackbox: "Removed" -> "MicroSD card slot"
    - Add blackbox.kicad_sch to schematic hierarchy listing
    - Uncomment board render images in README
2026-04-06 Update power specifications in README
2026-04-06 Fix battery spec: 2S-6S -> 3S-6S (10V buck needs >10.5V input)
2026-04-06 Add V0.3 known issues for V0.4 fix list, update open issues
    C28 voltage rating, R30 divider, L2 inductor value, LED0 color,
    LMR51430 upgrade path — all noted for next revision. CRIT-5 (ESC
    connector) marked fixed. OSD pin mapping updated to GPIO4-6.
    [OpenFC.kicad_pcb, OpenFC.kicad_sch, blackbox.kicad_sch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]
2026-05-07 alpha routing
    [OpenFC 2.kicad_pcb, OpenFC 2.kicad_sch, OpenFC.kicad_pcb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]
2026-05-27 Reorg: de-cloud, rename to OpenFC-Lite-Mini, Rev 1/2 docs overhaul (#1)
    * Remove iCloud duplicate files, de-cloud repo
    Repo lived in iCloud Drive, which spawned 252 ' 2'-suffixed duplicate
    files (kicad sources, 3D models, production exports) that got committed.
    Repo moved out of iCloud to /Users/stan/OpenDrone; deleting all dups.
    Every removed file had a verified non-dup counterpart still tracked.
    * Rename ECO -> Lite throughout, fix upstream link
    Product renamed OpenFC-ECO -> OpenFC-Lite (GitHub repo + remote already
    renamed). Updates README, CLAUDE.md, tool docs/scripts, fab archive name,
    image filenames, and the Beta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
    [OpenFC 2.kicad_pcb, OpenFC 2.kicad_sch, blackbox 2.kicad_sch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]
2026-05-27 Untrack generated analysis caches; fix .gitignore (#2)
    pcb.json / schematic.json are large auto-generated dumps with absolute
    iCloud paths baked in (stale after the repo moved out of iCloud). They
    regenerate from the KiCad sources, so untrack and gitignore them.
    Also stop ignoring CLAUDE.md — it is the canonical tracked project doc.
2026-05-27 Remove dead orphan schematic sheets (baro, compass, elrs) (#3)
    Unreferenced leftovers from the full OpenFC (barometer, compass, ELRS RX).
    Not in the Mini hierarchy; none of their parts are in the design. Kept
    leds.kicad_sch per request.
    [baro.kicad_sch, compass.kicad_sch, elrs.kicad_sch]
2026-05-29 Rev 2: fit 3A bucks, resolve power/LED/signal change-list items
    Schematic (power, rp2350a) + docs in sync with Rev 2 decisions:
    Power
    - U3/U4 bucks: LMR51420 (2A) -> LMR51430YFDDCR (3A, C5219261)
    - 10V FB R30 -> 6.49k (E96 stock) => Vout 9.85V
    - C28 10V output cap kept 22uF 16V X5R 0603 (digital-VTX rail)
    - L2/L3 both rails 4.7uH (XRTC303020D4R7MBCA)
    - U6 gyro LDO kept NCV8187 (300mA) for PSRR
    MCU/USB
    - R12/R13/R14 kept at 30R (DFM consolidation, no impact)
    - D1 USB ESD removed on schematic; flagged for restore (recommendation)
    LEDs
    - D2 LED0 -> blue XL-1005UBC; greens XL-1005UGC; all 0402
    - Series resistors recalculated for ~1mA: D2 510R, D7 680R, D5 2.4k, D4 7.5k
    Signals/decisions
    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
    [power.kicad_sch, rp2350a.kicad_sch]
